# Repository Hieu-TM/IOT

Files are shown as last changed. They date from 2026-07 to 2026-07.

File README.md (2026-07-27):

# Aqua Scope — Trạm Quan Trắc & Đếm Hạt/Rác Thải Vĩ Mô Trong Dòng Chảy (1mm–5mm)

Aqua Scope là dự án chuyển đổi một cụm camera (**baseline hiện tại: ESP32-CAM AI-Thinker, OV2640**; board gốc thử nghiệm là XIAO ESP32-S3 Sense, đã thay từ 2026-07-15, nay chỉ giữ làm biến thể cơ khí tham khảo) thành một **trạm chụp ảnh và đếm hạt tự động** đặt trong một **khối trụ chắn sáng**, camera nhìn thẳng xuống một **dòng chảy nước hở** để **phát hiện, đếm và đo kích thước** các hạt nhựa/rác thải vĩ mô cỡ **1mm – 5mm**.

> **Phạm vi trung thực về vật lý:** Hệ này **đếm và đo kích thước hạt/rác trong dòng chảy** bằng ảnh bóng đổ (silhouette). Nó **không** phân biệt hóa học "hạt này là nhựa hay không phải nhựa" — việc đó cần nhuộm huỳnh quang (Nile Red) và được ghi nhận là **hướng mở rộng tương lai**, không nằm trong baseline.

---

## Chạy hệ thống (đường ngắn nhất)

Bấm đúp **`start.bat`** ở thư mục gốc. Nó tự tạo môi trường ảo, cài thư viện ở
lần đầu, khởi động backend và mở `http://localhost:8000`.

Backend chạy trong một **cửa sổ PowerShell riêng** tên **"Aqua Scope Server"**
mà `start.bat` mở ra; cửa sổ `start.bat` ban đầu tự đóng ngay sau đó — đó là
bình thường, không phải lỗi. Muốn dừng server thì bấm **Ctrl+C** hoặc đóng
cửa sổ **"Aqua Scope Server"** (không phải cửa sổ đã đóng).

> **Trước khi bấm Bắt đầu:** `ml/config.toml` mặc định `backend = "local"`,
> nhưng repo này **không** kèm sẵn `ml/models/best.pt` (weights không commit
> được) và `ml/requirements-infer.txt` cũng cố tình không cài ultralytics/
> torch — nên trên một máy mới clone, bước 4 dưới đây sẽ báo lỗi 400
> "local.weights not found". Chọn một trong hai hướng trước:
> * đổi sang `backend = "roboflow"` trong `ml/config.toml` và điền
>   `roboflow.api_key` (+ workspace/workflow_id) vào `ml/config.local.toml`
>   (file này gitignore, không commit key); hoặc
> * cài `pip install -r ml/requirements.txt` rồi tự train/đặt weights vào
>   `ml/models/best.pt` (xem `[local]` trong `ml/config.toml`).

Trên dashboard:

1. Bấm **Dò** — tìm board qua `aqua-scope.local`. Không thấy thì gõ IP tay
   (Serial Monitor 115200 in ra IP lúc board khởi động).
2. Bấm **Canh sáng buồng tối** rồi **Lưu vào flash** (chỉ cần làm một lần cho
   mỗi rig — cấu hình được nhớ qua các lần mất điện).
3. Bấm **Bơm auto BẬT**.
4. Chọn **Xem** hoặc **Đo**, rồi bấm **Bắt đầu**.

Mỗi chu kỳ bơm sinh một khung ở pha lắng (SETTLING); hệ thống chạy tới khi bấm
**Dừng** — không còn giới hạn số ảnh.

| Chế độ | Ghi vào sổ audit? | Dùng khi |
|---|---|---|
| **Xem** | Không | canh sáng, chỉnh rig, thử nghiệm |
| **Đo** | Có, mỗi chu kỳ một mẫu | đo thật, cần truy xuất nguồn gốc |

> **Cảnh báo triển khai:** backend lắng nghe trên `0.0.0.0:8000` để mở được từ
> điện thoại trong cùng LAN, và **không có xác thực**. Đây là rig demo trong
> mạng nội bộ — đừng chuyển tiếp cổng này ra Internet.
>
> Chế độ **Đo** chạy dài sẽ tích ảnh trong `web/backend/data/images/`
> (~300KB/mẫu, chu kỳ 15s ≈ 70MB/giờ). Chưa có dọn rác tự động — tự theo dõi
> dung lượng đĩa nếu chạy nhiều giờ liền.

---

## 🎯 Bối Cảnh Ứng Dụng (Use Case)

**Kiểm soát chất lượng nước đầu vào cho nhà máy chế biến thực phẩm.** Hệ được đặt ở **điểm lấy nước đầu vào**, kiểm tra nước **trước khi** đưa vào dây chuyền sản xuất, nhằm phát hiện và định lượng hạt/rác vĩ mô (1–5mm) lẫn trong nguồn nước.

Đặc điểm bối cảnh này định hình các quyết định thiết kế:

| Đặc điểm bối cảnh | Hệ quả cho thiết kế |
|---|---|
| **Mẫu ổn định** (nước máy/nguồn cấp, không phải nước thải bẩn biến động mạnh) | Nền sáng đều và ngưỡng hóa (threshold) cố định là đủ tin cậy; không cần bù trừ nền phức tạp. |
| **Lấy mẫu định kỳ** (theo lô/theo ca, không phải giám sát liên tục 24/7) | Chu trình **Stop-Flow** rất hợp: mỗi lần đo là một mẫu rời rạc, có thời gian settle; không cần throughput cao. |
| **Yêu cầu truy xuất nguồn gốc (traceability)** | **Bắt buộc**: mỗi lần đo phải gắn **mã mẫu / timestamp / số hạt / phân bố kích thước** và **lưu lại (log)** để đối chiếu về sau. Đây là yêu cầu chức năng mới, không chỉ "đếm là xong". |

> **Lưu ý phạm vi:** đây là kiểm nước đầu vào của nhà máy thực phẩm, **không phải** thiết bị đạt chuẩn an toàn thực phẩm/y tế được chứng nhận. Baseline là **rig demo/phòng lab** minh họa quy trình kiểm định, không phải thiết bị thương mại đã kiểm chuẩn.

---

## 📌 Tiêu Chí Cốt Lõi (3 KHÔNG)

1. **KHÔNG chỉnh sửa thấu kính**: Giữ nguyên lens gốc. Thực nghiệm cho thấy lens gốc OV2640 **tự lấy nét macro sắc nét ở cự ly 3–5cm** — nên chỉ cần đặt mẫu đúng khoảng cách đó, **không cần vặn hay thay lens**.
2. **KHÔNG dùng chip vi lưu kín**: Hạt 1–5mm sẽ làm tắc/rò các kênh micron của flow-cell kín (như [pone.0244103.pdf](file:///c:/University/Semester%204/IOT102/project/pone.0244103.pdf)). Thay bằng **khay dòng chảy hở (Macro-Flow Stage)** + **mực nước cố định bằng mép tràn (weir)** và (tùy chọn) một **cửa sổ kính phẳng cố định** để làm phẳng mặt nước.
3. **KHÔNG can thiệp thủ công**: Bơm, chiếu sáng, chụp ảnh, đếm và xả đều tự động. *(Ngoại lệ thực tế: cần vệ sinh định kỳ chống bám bẩn/tảo khi dùng ngoài thực địa — hệ baseline định vị ở mức demo/phòng lab.)*

---

## 🏗️ Kiến Trúc Vật Lý

Khối trụ chắn sáng **ngắn** (~4–5cm), camera úp xuống từ nắp trụ, đèn nền trắng khuếch tán chiếu ngược từ dưới đáy khay trong suốt lên.

```mermaid
graph TD
    subgraph "Khối Trụ Chụp Ảnh (Imaging Tube)"
        T3["Nắp trụ tháo được: Camera ESP32-CAM (AI-Thinker) úp thẳng xuống"]
        T2["Thân trụ chắn sáng (~4-5cm): cố định cự ly nét 3-5cm + buồng tối"]
        T1["Đáy: Khay dòng chảy hở, đáy TRONG SUỐT (đĩa acrylic tròn); mực nước giữ bằng bơm-tắt (van tự chặn)"]
        B["Hộp đèn nền (Light Box): đèn chiếu GIÁN TIẾP vào nền trắng, ánh sáng dội ngược lên"]
    end

    subgraph "Trạm Bơm (đặt tách rời)"
        P["Bơm màng RS365 12V (chủ động hút/đẩy) + lưới thô >5mm ở cổng vào"]
    end

    P -->|Hút chuỗi: nguồn→khay→bơm→thải, ống ID≥6mm| T1
    T3 -->|Nhìn vuông góc, cự ly 3-5cm| T1
    B -->|Ánh sáng xuyên đáy trong| T3
```

### Vai trò của khối trụ (xương sống của hệ, không phải cái vỏ)
1. **Thước đo (datum):** cố định **cứng** cự ly camera↔nước → giữ **mm/pixel** ổn định → đo kích thước hạt đúng.
2. **Buồng tối:** chắn ánh sáng môi trường → phơi sáng ổn định, ngưỡng hóa (threshold) đáng tin.
3. **Chân máy:** tiết diện lớn, ngắn → cứng, chống rung → ảnh nét, khung hình không lệch.
4. **Nhà đèn:** giữ đèn nền + thành trong **sơn đen nhám** để hút phản xạ lạc.

Chuỗi phụ thuộc: `chiều cao ống → cự ly camera-nước → FOV → mm/pixel → hạt nhỏ nhất thấy được`. Vì lens nét ở 3–5cm nên ống ngắn ~4–5cm; ở cự ly này khay **lấp gần đầy khung hình** và **1mm ≈ 14–35 pixel** (tùy độ phân giải ảnh), thừa để đếm.

> **🔒 Hình dạng & lắp nắp (chốt):** thân trụ là **ống trụ THẲNG**, đường kính ngoài **bằng đúng footprint của base Matchboxscope ĐÃ IN (~50×52mm)** — **KHÔNG phình rộng thành "cốc"**, và **nắp trụ chính là base đã in** (tái dùng nguyên bản, bắt vít qua lỗ sẵn), không dựng nắp mới. Thử nghiệm cho thấy ống thẳng cho ảnh **không kém** ống rộng — chất lượng silhouette do **nội thất đen nhám + phơi sáng tay** quyết định, không do bề rộng ống. Vì nắp (base) chỉ ~50mm nên khay/cửa sổ acrylic/đèn nền **co theo cho lọt lòng ống** (`tube_id`≈46mm → vùng nước ảnh hóa ~40mm, vẫn lấp gần đầy khung, 1mm ≥ ~13px ở VGA).

---

## 🔬 Chiếu Sáng: Bóng Đổ Nền Sáng (Backlit Silhouette)

Đèn LED **trắng** đặt **dưới** đáy khay trong suốt, chiếu ngược lên qua nước. Hạt hiện thành **bóng đen sắc nét trên nền sáng đều**. Đây là kỹ thuật đo hạt kinh điển (shadowgraphy).

### Hộp đèn nền (Light Box) — "LED XUÔI" + buồng trộn + màng khuếch tán xếp lớp

> **🔒 CHỐT 2026-07-07 (thay phương án "bounce/baffle" cũ):** dùng **"LED xuôi"** — module LED
> dựng đứng, **đầu LED hướng THẲNG LÊN**, phía trên có **buồng trộn ~8mm** rồi **màng khuếch tán
> xếp lớp** (giấy can/mica mờ, thêm/bớt lớp chỉnh độ tán) ngay dưới đáy khay. Lý do: test thực tế
> với khuếch tán lớp giấy cho kết quả chấp nhận được; nước cấp nhà máy sạch/ổn định nên nguồn xuôi
> là đủ, kết cấu đơn giản hơn hẳn bounce. (Chi tiết: `thiet_ke_hop_den_nen.md`.)

Kết cấu xếp lớp từ dưới lên:

```
        [ Đáy khay: ĐĨA ACRYLIC trong suốt ]   ← hạt nằm trên đây
   ┌────────────────────────────────────┐
   │  MÀNG KHUẾCH TÁN xếp lớp 0–4mm      │  ← giấy can / mica mờ (chỉnh được)
   ├────────────────────────────────────┤
   │  BUỒNG TRỘN ~8mm (khử hotspot)      │
   │            ▲ LED                    │  ← module LED móc khoá 37.5×10×16
   │       [vách đỡ RỜI, 2 ốc M3 ngang]  │     dựng đứng, đầu LED hướng LÊN,
   │        nửa pin dưới vách            │     cắm-tháo ma sát qua lỗ vách
   └────────────────────────────────────┘
        vành đáy ống = chân đế (hở giữa để thay pin/thao tác)
```

- **Cả module móc khoá = "1 bóng"**: xỏ qua lỗ giữa vách đỡ (khe +0.4mm, giữ ma sát, không keo).
- **Vách đỡ là MIẾNG RỜI** nằm giữa lòng ống, bắt **2 ốc M3 xuyên ngang thành ống** — tháo 2 ốc
  là gỡ cả vách + module.
- **Mặt trong khoang đèn TRẮNG mờ** (khác thân trụ quang học đen nhám) để sáng đều thêm.
- **Màng khuếch tán là lớp bắt buộc**: nguồn điểm → nền xám đều; camera không bao giờ thấy LED trần.

### Bắt buộc để không bị cháy sáng (đúc kết từ thực nghiệm)
- **Khuếch tán** ánh sáng qua tấm mờ (acrylic mờ / giấy can) → nền **xám đều**, không có đốm chói.
- **Phơi sáng thủ công** trên firmware: **tắt AEC (auto exposure), tắt AEC DSP, tắt AGC (auto gain)**, đặt **Gain = 0** và **Exposure thấp**. *(Nếu chỉ kéo thanh Exposure mà chưa tắt AEC/AGC thì cảm biến ghi đè → luôn cháy trắng.)*
- **Vùng sáng lấp đầy khung hình**, tránh viền đen lớn (viền đen vừa phí pixel vừa đánh lừa auto-exposure).
- **Nếu dùng đèn pin mini (kiểu lồng đèn):** độ sáng yếu dần khi pin cạn → khóa phơi sáng tay rồi chỉnh Exposure khớp độ sáng thực; nếu đèn RGB/nhấp nháy thì **phải đặt về trắng tĩnh (static white)**, màu đổi sẽ làm nền chập chờn hỏng ảnh.

### Giảm cường độ khi sáng quá mạnh
- **Khuếch tán/làm đều:** 1–2 lớp **giấy can** hoặc **mica mờ** (mica bền hơn giấy khi gần nước; giấy dễ ẩm, cong).
- **Giảm độ sáng:** chồng thêm **giấy trắng thường** hoặc **phim ND (Neutral Density)** (ND giảm sáng không đổi màu).
- **Cách "sạch" nhất — hạ dòng đèn:** dùng **PWM/chiết áp/điện trở lớn hơn** để chỉnh vô cấp, ưu tiên cách này để tinh chỉnh cuối. *(Làm trước hết vẫn là khóa phơi sáng tay — nhiều ca "cháy sáng" là do AEC/AGC chứ không phải đèn quá mạnh.)*

---

## 🌊 Hệ Dòng Chảy (đơn giản, không kẹt)

- **Dòng chảy do BƠM CHỦ ĐỘNG** (không dựa trọng lực): một **bơm màng RS365 12V** (tự mồi) đặt ở **đầu ra**, hút cả chuỗi **nguồn → khay → bơm → thải**. Bật bơm thì nước (và hạt) bị kéo qua; **tắt bơm** thì **van 1 chiều trong bơm tự bịt, GIỮ NGUYÊN mực nước** để settle — **không cần mép tràn/standpipe để giữ mực** (xem ghi chú "Giữ mực & chống đọng").
- Nước mẫu + hạt vào khay qua **ống rộng** + **lưới thô khe >5mm** ở cổng vào (chỉ **chặn rác to** như lá/cành, **không lọc mất hạt cần đo**).
- **Nước luôn vào–ra qua cổng ở THÀNH BÊN** (theo phương ngang), **không đổ từ trên xuống băng qua cửa sổ** — tránh che tầm nhìn camera và tránh khuấy động mặt nước. Đĩa acrylic ở đáy chỉ có **nước đứng yên bên trên và ánh sáng bên dưới**.
- **2 cổng thành bên, ĐỐI TÂM 180°** để dòng quét ngang TOÀN sàn: (1) **VÀO** — biến tia thành **màng rộng sát đáy** bằng **khe khuếch tán (~18–22mm × ~3mm)** để xóa 2 thùy tĩnh hai bên và quét mặt đáy; qua lưới >5mm nối **nguồn mẫu**. (2) **RA — cổng rút SÁT ĐÁY** (KHÔNG phải ở đỉnh 6mm) nối **ống hút bơm RS365 → thải**, để lúc flush hút được cả **hạt CHÌM (PET/PS) nằm ở đáy**.
- **Mực nước 6mm** do **thời lượng bơm + van bơm tự chặn** ấn định. **Mép tràn (weir) hạ xuống vai trò TÙY CHỌN** (chặn-tràn an toàn khi fill + mực lặp lại), không còn là cơ cấu bắt buộc. **Van xả đáy** cũng tùy chọn (xả cạn/vệ sinh).
- **Chống đọng — yêu cầu duy nhất của khay là "mọi hạt phải RA HẾT, không sót":** **bo fillet R≥2.5mm** góc đáy–thành; **mặt đĩa acrylic phẳng bằng sàn + silicon vê tròn** mối nối để xóa rãnh bẫy hạt; **TUYỆT ĐỐI không lưới/gờ giữ hạt** (việc "giữ hạt lúc chụp" là do **bơm TẮT**, không do cơ học). Flush = **bơm chạy mạnh** (vận tốc khay ~10 cm/s ≈ Q ~1.4 L/min) đủ nhấc cả hạt nổi lẫn chìm ra cổng RA. **Kiểm bằng thả ~20 hạt rồi đếm hạt sót.**
- Ống **ID ≥ 6mm (≥3× hạt 2mm)** để không kẹt; nút hẹp thật sự là **van 1 chiều trong bơm** (bệ ~2–4mm). **Bơm tách rời khối quang** để cách ly rung chấn; nối khay bằng **ống của bơm RS365 đường kính 8mm** *(mặc định hiểu là ID danh nghĩa ~8mm → cổng/ngạnh khớp 8mm; nếu 8mm là OD thì ID~6, cần xác nhận)*. Điện: RS365 12V qua **MOSFET IRLZ44N + diode flyback 1N4007 + tụ 470–1000µF**, nguồn **adapter 12V/2A**, ESP32 nuôi riêng (USB 5V hoặc buck 12V→5V), **chung GND**.

### Độ dày lớp nước (~6mm) — vì sao phải MỎNG
Hạt nhựa **nổi HOẶC chìm** (PE/PP nổi ở mặt nước; PET/PS chìm ở đáy acrylic) → hạt nằm ở **2 mặt phẳng** cách nhau đúng bằng độ dày nước. Giữ nước **mỏng** để:
- **Cả hạt nổi lẫn hạt chìm cùng nằm trong vùng nét (DOF)** — nước sâu thì một trong hai lớp bị nhòe → đo sai kích thước.
- **Chống hạt xếp chồng theo phương đứng** (2 bóng đè nhau → đếm sai); nước mỏng ép hạt thành gần-một-lớp.

Sàn dưới = **hạt lớn nhất 5mm + ~1mm dư ⇒ chọn ~6mm**. Kèm theo: **lấy nét ở GIỮA lớp nước (~3mm)** để hạt nổi/chìm cách mặt nét đều nhau; và **phải kiểm DOF trên phần cứng thật** — nếu DOF của lens gốc ở 40mm < 6mm thì hạt nổi sẽ nhòe → hạ xuống 5mm (tham số hóa).

### Vì sao chuyển sang bơm màng chủ động (bỏ nhu động 28BYJ-48 + bỏ trọng lực)
Bơm nhu động 28BYJ-48 (tham khảo Planktoscope Mini) **bị loại vì quá chậm**: hộp số 1/64 → trục ra ~10–15 RPM, kịch trần ~40 RPM (mô-men sụt theo bậc), lưu lượng thực chỉ **vài mL/phút** → đổ đầy khay 7–10 mL mất **hàng phút**, trong khi ESP32-S3 xử lý xong tức thì. Bơm là **nút cổ chai duy nhất**. Ép nó nhanh (full-step, quá áp, bỏ hộp số) đều đi ngược bản chất "định lượng lưu lượng thấp".

Baseline dùng **bơm màng RS365 12V chủ động** cho toàn bộ fill/flow/flush:

| Việc | Ai làm |
|---|---|
| Cấp mẫu **VÀO** + tạo dòng | **Bơm RS365** hút chuỗi nguồn→khay→bơm→thải |
| **Giữ mực nước** khi chụp | **Van màng bơm tự chặn khi TẮT** (mép tràn = tùy chọn chặn-tràn, không bắt buộc) |
| **Xả/flush hạt** ra ngoài | **Bơm RS365** chạy mạnh/lâu hơn, cuốn hạt (nổi + chìm) ra **cổng ra sát đáy** → thải |

> **Đánh đổi (ghi trung thực):** dòng chủ động khiến **hạt đi qua bơm** ở phía cổng ra — khác thiết kế gốc *"hạt không bao giờ qua bơm"*. Chấp nhận được vì **phạm vi test là hạt < 2mm**, nhỏ hơn nhiều bệ van màng (~2–4mm). Nếu sau này quay lại dải 5mm thì **phải xét lại** (5mm cứng sẽ kẹt van). Bơm chìm 5V bị loại vì phải ngâm nước (khuấy mặt nước + phơi nhiễm hạt) và **cháy khi chạy khô**.

### Cấu tạo đáy khay: đĩa acrylic tròn + chống rò
Đáy trong suốt dùng **đĩa acrylic (mica) TRONG** cắt tròn làm "cửa sổ". Nhựa in 3D **không cho sáng xuyên đều** (các lớp in tán xạ), nên chỉ dùng in 3D làm **khung đen chắn sáng**, còn cửa sổ sáng là **tấm trong rời lắp vào**. **Chọn acrylic thay lam kính** vì lam kính cố định kích thước (rộng chỉ 26mm) không phủ được khay tròn Ø40 → phải bóp vùng ảnh nhỏ; **acrylic cắt được đĩa tròn Ø bất kỳ** nên **giữ nguyên khay tròn, vùng ảnh lấp đầy khung**. Chụp silhouette không cần độ trong quang học cao (hạt nằm ngay trên tấm, đèn đã khuếch tán) nên acrylic thừa trong.

> **Tách 2 lớp — đừng gộp:** cửa sổ đáy = **acrylic TRONG** (để bóng hạt nét); tấm khuếch tán = **mica MỜ/giấy can RIÊNG** đặt bên dưới (để đều sáng). Hai chức năng, hai tấm.

Kiểu lắp **gờ đỡ + vòng ép + silicon**:

```
   mặt cắt cạnh khay:
   ┌── vòng ÉP (retainer, vặn vít/ngàm cài) ──┐
   ═════════ ĐĨA ACRYLIC TRONG ═════════       ← ép giữa 2 lớp
   ░silicon░                        ░silicon░   ← keo silicon hồ cá
   └─ gờ KÊ (ledge) ─┐        ┌─ gờ KÊ ─┘
        thành nhựa in 3D (đen mờ)
```

- **Kích thước đĩa:** cắt **Ø hơi lớn hơn miệng khay** (VD Ø42 cho khay trong Ø40, lọt bore ID46) để có mép chồng lên gờ; **dày 2–3mm** (đĩa Ø~42 không võng), ưu tiên **acrylic đúc (cast)**.
- **Gờ kê (ledge):** hốc lõm quanh miệng khay, ăn vào trong ~2.5mm, sâu ≈ (độ dày đĩa + ~0.3mm cho silicon).
- **Chống rò:** bơm viền mỏng **silicon trung tính (keo hồ cá)** lên gờ **trước khi** đặt đĩa, ấn nhẹ cho dàn đều. **KHÔNG dùng keo 502/cyanoacrylate** — hơi keo làm **acrylic mờ trắng (fogging)**. Không lau bằng dung dịch gốc amoniac (gây rạn).
- **Giữ cố định:** một **vòng ép in 3D thứ hai** đè lên viền đĩa, bắt **3–4 vít M2.5** hoặc ngàm snap-fit → vừa kín, vừa không cho đĩa trôi/nổi.
- **Dung sai in:** chừa khe **+0.3–0.4mm** quanh đĩa; in khung **đen mờ, mặt trong tối** để chắn sáng lạc.
- **Acrylic dễ xước** → vết xước có thể đọc thành "hạt ảo"; thiết kế cửa sổ là **chi tiết thả-vào thay được**, lau nhẹ bằng khăn mềm.
- Tùy chọn (đúng "3 KHÔNG" #2): thêm **1 tấm phẳng gác trên gờ phía trên** (acrylic hoặc lam kính) làm **cửa sổ ép phẳng mặt nước** — **gác gờ, không thả nổi** (kính/acrylic nặng hơn nước sẽ chìm). Lam kính đang có tận dụng ở đây hoặc để hiệu chuẩn.

---

## ⚙️ Chu Trình Vận Hành (Stop-Flow)

```mermaid
sequenceDiagram
    autonumber
    participant Bom as Trạm Bơm
    participant Den as Đèn Nền Trắng
    participant Cam as Camera (ESP32-CAM)
    participant CV as Xử lý ảnh (PC/laptop qua ml/)

    Note over Bom, CV: B1: Cấp mẫu
    Bom->>Bom: Bơm RS365 hút chuỗi nguồn→khay→thải, khay đầy tới mép tràn

    Note over Bom, CV: B2: Đóng băng (Settle)
    Bom->>Bom: TẮT bơm 1-2s; van màng bơm tự chặn giữ mực nước, mặt nước phẳng lại

    Note over Bom, CV: B3: Chụp ảnh
    Den->>Den: Bật đèn nền trắng (ổn định)
    Cam->>Cam: Chụp ảnh độ phân giải CAO (SXGA/UXGA)

    Note over Bom, CV: B4: Đếm & Đo + Phân loại
    CV->>CV: PC/laptop kéo ảnh, chạy YOLO (local hoặc Roboflow) → bbox + class + confidence; size_mm = max(w,h) / px_per_mm

    Note over Bom, CV: B5: Xả mẫu
    Den->>Den: Tắt đèn
    Bom->>Bom: Bơm RS365 chạy mạnh cuốn hạt ra cổng ra → thải, nạp mẫu mới → lặp
```

> **Vì sao PHẢI dừng dòng khi chụp (Stop-Flow là bắt buộc, KHÔNG phải di sản bơm nhu động):** dừng dòng cần cho **quang học + thuật toán**, độc lập với loại bơm:
> 1. **Rolling shutter** của OV2640 (mỗi hàng pixel phơi sáng lệch giờ) làm hạt đang trôi **méo hình (skew) + nhòe** → sai phép **ĐO KÍCH THƯỚC**. (Chụp lúc chảy cần global shutter hoặc đèn strobe freeze — hệ này không có.)
> 2. Mặt nước chảy **gợn sóng** → khúc xạ bóng hạt, lệch vị trí/kích thước biểu kiến. Settle 1–2s làm mặt phẳng lại.
> 3. Đếm cần **mẫu RỜI RẠC, thể tích cố định** (1 ảnh = N hạt trong diện tích khay × 6mm) → quy ra nồng độ + truy xuất nguồn gốc.
> 4. Pipeline `threshold → connected components → count` là thuật toán **MỘT KHUNG** → chạy trên dòng đang chảy sẽ **đếm đôi** cùng một hạt.
>
> ⇒ Bơm màng RS365 nhanh **làm Stop-Flow TỐT HƠN** (Fill/Flush chớp nhoáng → chu kỳ ngắn, nhiều mẫu/phút), **không hề làm nó thừa**. Thứ *thực sự* đã lỗi thời (thời nhu động) là logic "trọng lực đổ đầy / bơm chỉ chuyển nước sạch / xả van đáy" — xem `info.txt §5–6`.

---

## 🧠 Xử Lý Ảnh

**Hiện trạng đang chạy:** ESP32-CAM chỉ chụp/phục vụ ảnh (`/capture`, `/stream`); một PC/laptop kéo ảnh về và chạy **YOLO** (local `ultralytics` hoặc Roboflow Workflow API — xem `ml/deploy_options.md`) để lấy bbox + class + confidence, suy ra `size_mm = max(w,h) / px_per_mm`, rồi gửi kết quả lên backend. Lý do offload: board ESP32-CAM hiện dùng (ESP32 thường) không có lệnh vector AI như dòng S3 mà thiết kế gốc bên dưới giả định.

**Thiết kế gốc (viết cho phần cứng XIAO ESP32-S3, chưa áp dụng lại được trên ESP32-CAM hiện tại):** pipeline lai — **classical CV** lo **đếm + đo kích thước** (chính xác, rẻ, không cần train), rồi **classifier nhỏ on-device** lo **phân loại từng hạt là GÌ**.

**Vì sao KHÔNG để object detection làm hết (lý do gốc, khi còn nhắm tới on-device S3):** FOMO trên XIAO S3 chạy input ~96×96, ~143ms/~7fps nhưng **chỉ trả centroid, KHÔNG trả kích thước**; ở FOV ~40mm thì 96×96 ≈ 0.42mm/px → hạt <2mm chỉ ~5px, dễ mất hoặc dính chùm sau downsample. Lập luận này áp dụng cho FOMO/end-to-end detection *chạy trên chip*; pipeline YOLO hiện tại chạy trên PC nên không bị giới hạn 96×96 đó, nhưng đổi cách tính size từ "connected components" sang "bbox / px_per_mm" — hai cách này CHƯA được đối chiếu độ chính xác với nhau.

**Pipeline gốc (dự kiến, chưa chạy trên phần cứng hiện tại):**
1. **Chụp phân giải cao** (SXGA/UXGA) → ảnh xám → **ngưỡng hóa** (vùng tối trên nền sáng) → **connected components** → mỗi blob cho **tâm + diện tích → đếm & phân bố kích thước**.
2. **Crop từng blob** → đưa vào **classifier nhỏ** (TinyML, tận dụng lệnh vector AI của S3) → **gán loại hạt**. *(Danh sách lớp cụ thể — ví dụ nhựa / bọt khí / rác hữu cơ / sợi — sẽ chốt sau khi có dữ liệu mẫu thật.)*

**Phần cứng dự kiến cho pipeline gốc:** chạy **on-device** trên XIAO ESP32-S3 (PSRAM 8MB, 240MHz, có lệnh vector AI) — không phải phần cứng ESP32-CAM đang dùng hiện tại.

*(Phân biệt nhựa/không-nhựa bằng hóa học vẫn là hướng mở rộng: nhuộm Nile Red + LED 365nm + kính lọc vàng → cấp thêm đặc trưng màu cho nhánh classifier, không thuộc baseline.)*

---

## 🗒️ Lịch Sử Thiết Kế (vì sao baseline hiện tại khác bản đầu)

Bản ý tưởng đầu (huỳnh quang UV + FOMO + kính nổi + cự ly 10–15cm + cột Z-Axis) đã được **sửa lại sau khi kiểm tra vật lý và thực nghiệm**:

| Vấn đề bản cũ | Sửa trong baseline |
|---|---|
| UV không làm đa số nhựa (PE/PP/PET/PS) phát quang; rác hữu cơ lại phát quang | Đổi sang **backlit silhouette** ánh sáng trắng, phát biểu mục tiêu trung thực (đếm hạt, không nhận dạng hóa học) |
| FOMO 96×96 không thấy hạt <2mm, không trả kích thước | **Hybrid**: classical CV đếm+đo (size chính xác) + **classifier** phân loại từng hạt (dùng thế mạnh AI của S3) |
| Kính thủy tinh "thả nổi" sẽ chìm | **Cửa sổ kính cố định + mép tràn** giữ mực nước phẳng |
| Bơm nhu động 28BYJ-48 quá chậm (~vài mL/phút) | **Bơm màng RS365 12V chủ động** lo fill/flow/flush; chấp nhận hạt <2mm qua bơm (đánh đổi có chủ đích) |
| Cự ly 10–15cm + lens gốc → hạt bé, phí pixel, cột conson rung | Thực nghiệm: lens gốc **nét ở 3–5cm** → ống **ngắn, cứng**, khay lấp đầy khung |

---

## 📁 Cấu Trúc Thư Mục

* [info.txt](file:///c:/University/Semester%204/IOT102/project/info.txt): Báo cáo kỹ thuật chi tiết (Tiếng Việt).
* [implementation_plan.md](file:///c:/University/Semester%204/IOT102/project/implementation_plan.md): Kế hoạch dựng mô hình 3D OpenSCAD + bảng hằng số baseline.
* [technical_specs.md](file:///c:/University/Semester%204/IOT102/project/technical_specs.md): Thông số cơ khí trích xuất từ các tệp STL tham khảo.
* `plan.md`: Kế hoạch build mô hình 3D (quyết định chốt G1–G5 + thứ tự + kiểm chứng).
* [`thiet_ke_hop_den_nen.md`](file:///c:/University/Semester%204/IOT102/project/thiet_ke_hop_den_nen.md): Chi tiết thiết kế hộp đèn nền "LED xuôi" (chốt 2026-07-07).
* `HUONG_DAN_LAP_RAP.md`: Tutorial thực thi — từ chi tiết đã in/đã mua → lắp trạm hoàn chỉnh → nạp firmware.
* `ai_model_plan.md`: Kế hoạch tạo & train model AI (classifier phân loại hạt) trong pipeline hybrid.
* `web_plan.md`: Spec+plan gộp bản đầu của web/backend — **đã superseded 2026-07-14**, giữ để tra cứu bối cảnh; nguồn sự thật hiện tại là cặp spec/plan trong `docs/superpowers/` (xem bên dưới).
* `openscad/` **(ĐÃ DỰNG 2026-07-07, tiếp tục sửa)**: mô hình OpenSCAD hoàn chỉnh — `constants.scad` (hằng số + assert),
  `components/*.scad` (bản mới nhất của mỗi chi tiết thắng — vd. `top_cap_004` thay `_001`–`_003`),
  `aqua_scope_assembly_001.scad` (lắp ghép tổng, cờ `explode`/`show_*`/`cam_variant`),
  `print/*.scad → *.stl` (9 chi tiết in, đã kiểm manifold). Kiến trúc **lắp từ đáy**: vỏ 1 ống liền
  (đen trên/trắng dưới), khay + đĩa acrylic + vòng ép snap-fit + màng + vách LED đều luồn/tháo từ dưới;
  2 khe dọc ±X cho ngạnh ống nước (có nút bịt chống lọt sáng). Biến thể **ESP32-CAM** (`cam_variant=1`)
  là baseline hiện tại; bản gốc XIAO chỉ còn giữ làm biến thể tham khảo.
* [base/](file:///c:/University/Semester%204/IOT102/project/base): STL bệ gốc Matchboxscope — **chính là nắp trụ** (in sẵn, tái dùng nguyên bản, không dựng nắp mới). **Đường kính thân trụ lấy đúng footprint của base (~50×52mm)**, ống THẲNG không phình rộng.
* [perestaltic pump/](file:///c:/University/Semester%204/IOT102/project/perestaltic%20pump): STL bơm nhu động Planktoscope Mini — **chỉ tham khảo, ĐÃ LOẠI** (quá chậm). Baseline dùng **bơm màng RS365 12V** chủ động.
* [`so_do/`](file:///c:/University/Semester%204/IOT102/project/so_do): Sơ đồ tổng quan hệ thống + chi tiết hộp đèn nền (SVG).
* [`firmware/`](file:///c:/University/Semester%204/IOT102/project/firmware): Firmware ESP32. Bản **chính thức**: [`aqua_scope_station/`](file:///c:/University/Semester%204/IOT102/project/firmware/aqua_scope_station) (ESP32-CAM AI-Thinker, port từ `esp32-cam-webserver` easytarget + `/device` audit + lưu cấu hình flash). Các thư mục khác (`aqua_scope_cam/`, `Esp32 cam/`, `esp32-cam-webserver/` repo lồng, `pump_stopflow_test/`) là tiền đề/tham khảo/công cụ test độc lập — xem bảng phân loại trong README của `aqua_scope_station/`.
* [`dataset_collector/`](file:///c:/University/Semester%204/IOT102/project/dataset_collector): Firmware (bản sao của `esp32-cam-webserver`, thêm nút thu dataset vào web UI) + `collect_dataset.py` + `diagnose.py` — công cụ thu ảnh dataset huấn luyện, tách riêng khỏi firmware của trạm.
* [`ml/`](file:///c:/University/Semester%204/IOT102/project/ml): Pipeline detection (Roboflow `microplastics-m7mf5`) — train/export/suy luận (2 nhánh backend Roboflow hoặc local `ultralytics`), `--from-board` chụp thẳng từ board ghi sổ audit. Xem `ml/deploy_options.md` cho 2 hướng deploy (offload PC vs on-device).
* [`web/`](file:///c:/University/Semester%204/IOT102/project/web): Backend FastAPI + dashboard truy xuất nguồn gốc (traceability) — nhận kết quả từ `ml`, phục vụ lịch sử/audit theo mã mẫu. Spec/plan hiện hành ở `docs/superpowers/specs|plans/2026-07-14-web-*`.
* [`Aqua Scope dashboard/`](file:///c:/University/Semester%204/IOT102/project/Aqua%20Scope%20dashboard): Design handoff (HTML/JSX tham chiếu, không phải code sản phẩm) cho dashboard QC ở `web/` — đã hiện thực hoá với vài lệch có chủ đích (SVG server-render thay Chart.js, bỏ Google Fonts/state-simulator).
* [`variants/`](file:///c:/University/Semester%204/IOT102/project/variants): Hướng nghiên cứu thay thế — cảm biến quang tán xạ 1D (photodiode + NeuralCasting), bỏ camera/holography và bỏ Stop-Flow. Không phải baseline, xem `variants/README.md`.
* [`docs/superpowers/`](file:///c:/University/Semester%204/IOT102/project/docs/superpowers): Spec/plan hiện hành theo chuẩn superpowers (`specs/`, `plans/`, `prompts/`) — nguồn sự thật mới nhất cho web, ml, firmware station/dataset-collector, thay cho các file `*_plan.md` rời ở gốc repo khi đã được đánh dấu superseded.

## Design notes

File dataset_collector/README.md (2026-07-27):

# Aqua Scope — Bộ thu thập dataset (ESP32-CAM)

Firmware + script để **chụp ảnh trên ESP32-CAM và kéo về laptop** làm dataset huấn luyện.

Tách riêng khỏi `firmware/` (nơi chứa 3 bản web-cam thông thường) vì đây là một
công cụ hoàn chỉnh gồm cả hai nửa: phần chạy trên board và phần chạy trên máy.

```
dataset_collector/
├── firmware/            ← nạp vào ESP32-CAM AI-Thinker
│   ├── firmware.ino         bản esp32-cam-webserver, đã cắt OTA/mDNS/NTP/portal
│   ├── app_httpd.cpp        web server — GIỮ NGUYÊN, không sửa dòng nào
│   ├── index_ov2640.h       web UI + khối "thu dataset" thêm vào
│   ├── index_ov3660.h       bản UI cho sensor OV3660 (giữ đồng bộ với trên)
│   ├── storage.{h,cpp}      lưu cấu hình camera vào SPIFFS
│   └── myconfig.h  camera_pins.h  css.h  index_other.h  src/
├── collect_dataset.py   ← chạy trên laptop: nhận ảnh (--serve) hoặc kéo ảnh
└── tests/               ← 38 test
```

## Phân chia trách nhiệm

| | Firmware | Trình duyệt | `collect_dataset.py` |
|---|---|---|---|
| Làm gì | phục vụ ảnh qua HTTP | cầu nối: lấy `/capture` rồi đẩy sang PC | ghi file vào dataset |
| Không làm gì | không biết dataset, không biết địa chỉ PC | không lưu gì | không chỉnh camera |

Firmware không mang HTTP client và không cần biết địa chỉ laptop — **toàn bộ việc
nối hai đầu nằm trong đoạn JS của trang web**. Nhờ vậy đổi cách thu dataset không
phải nạp lại firmware.

---

## Bước 1 — Nạp firmware

`dataset_collector/firmware/` là **bản sao của `firmware/esp32-cam-webserver/`**
(bản port easytarget đã sửa cho core 3.x + nút Dark), đã cắt bớt và thêm phần thu
dataset. Chọn bản này vì nó chạy **XCLK 8MHz** thay vì 20MHz — đó là nguyên nhân
của ảnh sọc/ám xanh trên các bản dựng từ ví dụ stock của Espressif.

Arduino IDE, gói board **esp32 by Espressif ≥ 3.0**:

| Mục | Chọn |
|---|---|
| Board | **AI Thinker ESP32-CAM** |
| Partition Scheme | **Huge APP (3MB No OTA/1MB SPIFFS)** |

WiFi sửa trong `myconfig.h`. Nạp: nối **IO0 → GND**, cấp nguồn, Upload, rút IO0, reset.

## Bước 2 — Canh sáng (một lần)

Mở `http://<IP>/` → bấm **Dark** (áp preset silhouette backlit) → chỉnh slider tới
khi **nền xám đều, hạt = bóng đen rõ**, không có đốm chói.

Vẫn còn sọc/ám màu? Hạ **xclk** trong Settings (8 → 6 → 4 MHz). Ảnh chậm hơn chút
nhưng sạch hơn — với Stop-Flow thì không ảnh hưởng gì.

Chỉnh xong bấm **Save** để ghi vào SPIFFS, lần sau cắm điện là đúng luôn.

## Bước 3 — Thu dataset

**Cách 1 — bấm nút ngay trên web (tiện nhất khi ngồi cạnh máy):**

```bash
python collect_dataset.py --serve          # để cửa sổ này chạy
```
Script in ra địa chỉ dạng `192.168.1.20:8765`. Điền vào ô **Dataset PC** trong
Settings của web UI (trình duyệt nhớ giúp, chỉ nhập 1 lần), đặt **Burst** = số ảnh
mỗi lần bấm, rồi bấm nút **💾 Dataset**. Trạng thái hiện ngay cạnh nút.

**Cách 2 — laptop kéo hàng loạt (khi cần số lượng lớn, không cần ngồi canh):**

```bash
python collect_dataset.py --host 192.168.1.50 --count 200 --interval 1.5
```

Ảnh lưu vào **`web/backend/data/dataset/`**, tên `YYYYmmdd-HHMMSS-mmm.jpg`.

| Tham số | Mặc định | |
|---|---|---|
| `--host` | *bắt buộc* | IP lấy từ Serial Monitor |
| `--count` | 1 | số ảnh |
| `--interval` | 1.5 | giây nghỉ giữa 2 ảnh |
| `--out` | `web/backend/data/dataset` | thư mục lưu |
| `--timeout` | 15 | timeout mỗi request |
| `--retries` | 3 | số lần thử lại mỗi ảnh |

Ctrl+C dừng giữa chừng — ảnh đã lưu vẫn còn nguyên.

---

## Vì sao lưu ở `data/dataset/` chứ không phải `data/images/`

`web/backend/data/images/` là kho ảnh **của các Sample trong DB**: mỗi file khớp
đúng một dòng, tên cứng `{sample_code}.jpg`
([ingest.py](../web/backend/app/routers/ingest.py)). Đổ ảnh thô vào đó sẽ tạo
file mồ côi — web không hiển thị được, lại lẫn với ảnh `MOCK-*` của
`mock_sender.py`. `data/dataset/` nằm cùng khu `data` nhưng không đụng vào mô
hình dữ liệu của web.

> **Lưu ý:** toàn bộ `web/backend/data/` bị **git-ignore**. Với dataset thì hợp lý
> (không nên commit hàng trăm JPEG), nhưng nghĩa là **xóa thư mục là mất trắng** —
> git không cứu được. Tự backup nếu dataset đã tốn công thu.

## Khác gì `firmware/esp32-cam-webserver/`

Toàn bộ đường camera (`StartCamera()`, `app_httpd.cpp`, prefs SPIFFS, cả 3 file
giao diện) **giữ nguyên không sửa** — đó là lý do chọn bản này. Chỉ có 2 thay đổi:

**1. Cắt 4 thư viện mạng:** OTA, mDNS, NTP, captive portal + DNSServer. Không cái
nào đụng vào camera, nhưng mỗi cái chạy task nền ăn heap — thứ ESP32-CAM vốn đã
thiếu khi chụp UXGA. Đo được: **41% → 39% flash, 75.9KB → 69.7KB RAM tĩnh.**

Các biến cờ (`otaEnabled`, `haveTime`, `captivePortal`) được giữ lại và đặt cứng
`false` vì `app_httpd.cpp` tham chiếu tới chúng — nhờ vậy file đó không phải sửa
một dòng nào.

**2. Thêm khối thu dataset vào web UI:** nút **💾 Dataset**, ô **Dataset PC**, ô
**Burst**, và dòng trạng thái. Thêm vào **cả** `index_ov2640.h` lẫn
`index_ov3660.h` — giao diện được chọn theo sensor lúc chạy, chỉ thêm một file thì
gặp board sensor khác là mất nút mà compile vẫn sạch.

## Ảnh trắng xóa / hỏng → chạy `diagnose.py` trước

```bash
python diagnose.py --host 192.168.1.50
```

Nó tắt đèn GPIO4 + mọi chế độ tự động, rồi **quét exposure từ 0 đến 1200** và đo
độ sáng từng ảnh. Kết quả trả lời dứt điểm một câu hỏi:

| Kết quả | Nghĩa là |
|---|---|
| Ảnh tối dần khi giảm exposure | Phần cứng bình thường, chỉ là canh sáng. Công cụ in luôn mức exposure nên dùng. |
| **Trắng ở mọi mức exposure** | Cảm biến không phản ứng. Chỉnh thông số vô ích → soi ánh sáng lọt vào, cáp ribbon, module. |

Đừng đoán mò khi ảnh trắng — hai trường hợp trên nhìn giống hệt nhau nhưng cách
sửa ngược nhau hoàn toàn.

**Nghi phạm số 1 khi trắng ở cả stream lẫn capture:** đèn flood **GPIO4** ngay
cạnh ống kính. `app_httpd.cpp` bật nó cho cả hai đường khi `lamp` ≠ 0 hoặc
`autolamp` bật. Trong ống chụp kín, nó bật là trắng xóa. Giữ **Light = 0**.

## Trục trặc khác

| Hiện tượng | Nguyên nhân thường gặp |
|---|---|
| **Ảnh sọc ngang / ám xanh lục** | XCLK quá cao. Hạ `xclk` trong Settings: 8 → 6 → 4 MHz. |
| Ảnh lỗi liên tục, board reset | **Brownout**: WiFi TX + chụp UXGA cùng lúc. Giảm Burst, tăng `--interval`, dùng nguồn 5V ≥ 2A. |
| Nền trắng xóa, không thấy hạt | Chưa bấm **Dark**, hoặc chỉnh xong quên bấm **Save**. |
| Bấm Dataset → `khong ket noi duoc ...` | Chưa chạy `collect_dataset.py --serve`, hoặc nhập sai IP/cổng, hoặc Windows Firewall chặn cổng 8765. |
| Bấm Dataset → `PC tu choi (HTTP 400)` | Ảnh tới nơi bị hỏng (thường do brownout giữa lúc truyền). Ảnh hỏng **không** được ghi vào dataset. |

## Chạy test

```bash
cd dataset_collector
python -m pytest tests/ -q      # 38 test
```

- **Chiều kéo + chiều nhận** đều test bằng **HTTP server thật** trên localhost,
  không mock `requests` — các kiểu hỏng cần bắt đều nằm ở tầng giao thức (body
  cụt, trả HTML kèm HTTP 200, preflight CORS, Content-Length nói dối), mock sẽ bỏ lọt.
- **Giao diện web** được kiểm bằng cách đối chiếu ID: mọi `getElementById` phải có
  phần tử tương ứng trong HTML, và khối JS ở 2 file index phải giống hệt nhau. Gõ
  sai một ID thì firmware vẫn compile sạch, vẫn nạp được, chỉ tới lúc bấm nút mới
  phát hiện im ru — đây là loại lỗi trình biên dịch không bao giờ thấy.

## Khác gì `ml.infer --from-board`

Hai công cụ, hai mục đích, cố ý không gộp:

| | `collect_dataset.py` | `ml.infer --from-board` |
|---|---|---|
| Mục đích | thu ảnh thô để **train** | đo mẫu thật để **ghi sổ audit** |
| Đầu ra | file JPEG trong `data/dataset/` | dòng Sample + Particle trong DB |
| Chạy suy luận | không | có |

Gộp lại sẽ buộc công cụ thu dataset phải mang theo cả detector lẫn kết nối DB
— hai thứ nó không cần.

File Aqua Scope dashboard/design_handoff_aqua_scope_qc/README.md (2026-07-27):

# Handoff: Aqua Scope — QC Dashboard

## Overview
Aqua Scope is a read-only QC dashboard for a water-quality monitoring station in a food-processing plant. It traces particle samples captured by a backlit imaging device (`aquascope-01`): dashboard overview, a filterable history/audit table, a per-sample detail view (image + bbox overlay + particle table + histogram + raw JSON), and a live "stream demo" canvas simulation. UI copy is Vietnamese throughout. Data model is append-only — there are no edit/delete affordances anywhere by design.

## About the Design Files
The files in this bundle (`Aqua Scope QC.dc.html`, `support.js`) are **design references built in HTML/React-like JSX**, not production code to copy directly. They render as a single-page app with client-side view switching (no router, no backend — all data is a hardcoded mock array and synthetic image generation). Your task is to **recreate this design in the target codebase's actual stack** (its component library, routing, state management, real API calls) — reproducing the exact layout, spacing, color, typography, and interaction behavior described below, not the literal markup.

## Fidelity
**High-fidelity.** Colors, spacing, type sizes, and component states are final. Treat hex/px values below as exact. The particle bbox synthesis and canvas stream simulation are demo-only stand-ins for a real detection feed/image — implement those against real backend data instead of porting the mock math.

## Design System
Built on the **Modernist** design system's structural principles (Archivo typeface, flat surfaces, thin 1px hairline borders, flush-left labels, generous spacing, 8-12px card radii) combined with a custom domain color palette (teal/amber/blue + a 5-color particle-label map) that carries QC meaning and should NOT be swapped for Modernist's red accent — the color-to-meaning mapping is a functional requirement of this product, not a brand choice.

## Screens / Views

### 1. Dashboard (`Bảng điều khiển QC`)
**Purpose:** At-a-glance shift summary + latest sample + quick nav to history.
**Layout:** Left sidebar (236px, fixed) + main content area. Content max-width 1180px, vertical flex, 20px gaps.
- **Metric tile row**: CSS grid, `repeat(auto-fit, minmax(190px,1fr))`, 14px gap. 4 tiles: "Mẫu hôm nay" (sample count), "Tổng hạt hôm nay" (total particle count), "Tỉ lệ nhựa" (plastic % in teal text), "Cảnh báo" (warning count — tile background switches to amber-bg (`#FAEEDA` light / `rgba(239,159,39,.15)` dark) when count > 0, otherwise neutral `--surface-1`). Tile padding 16px 18px, radius 8px (`--r-tile`). Value text 30px/600, label 12.5px, hint caption 11.5px `--text-3`.
- **2-column row** (`1.5fr / 1fr`, 20px gap, collapses to 1 column ≤900px): "Mẫu mới nhất" card (status chip + link to detail + backlit image + 4-row metadata list) beside "Phân bố loại" card (132px donut chart with center total label + color-swatch legend list with %).
- **Recent samples table**: last 5 today's samples, columns Mã mẫu / Mã lô / Giờ chụp / Số hạt / Trạng thái, row click opens detail. Header row 11px/500 `--text-2`.
- Collapsible "Ghi chú thiết kế" note block (`<details>`) at bottom explaining layout rationale — informational only, can be dropped in production.
- **Empty state**: icon + title + message centered card, shown when no samples loaded.

### 2. History / Audit (`Lịch sử · audit`)
**Purpose:** Dense, filterable audit log of all samples; CSV export.
**Layout:** Filter bar (from-date, to-date, lot-code select, clear-filters button, CSV export button) in a bordered card, 16px 18px padding. Below: result count summary caption, then a dense data table (min-width 820px, horizontal scroll on overflow) with columns Mã mẫu (monospace) / Mã lô / Thời gian chụp / Số hạt (right-aligned) / Phân bố loại (colored count chips per label) / Trạng thái (status chip) / row action link "Chi tiết →". Row height ~12px vertical padding, 1px top border between rows, no card-per-row. Pagination controls bottom-right (10 rows/page).
**States:** loading (shimmer skeleton rows), error (centered icon + retry button), empty (no filter matches), normal.
**Note:** No edit/delete UI anywhere — data is append-only.

### 3. Sample Detail (`Chi tiết mẫu`)
**Purpose:** Full inspection of one sample's backlit image + detected particles.
**Layout:** 2-column grid `1.35fr / 1fr` (stacks on mobile), left column sticky (`top:76px`) containing the backlit image card with SVG bbox overlays (colored per label, dashed for "unknown", labeled tag on hover) and a color legend row below. Right column (16px gap, stacked cards): metadata card (2-col key/value grid: Mã lô, Thiết bị, Giờ chụp, Giờ nhận, Hiệu chuẩn px/mm, Kích thước ảnh), particle table (Nhãn / Tin cậy / Kích thước / Diện tích / Tâm x,y — hover row ↔ hover bbox is bidirectional), size histogram (bar chart, fixed 0.3mm bins, 0–5mm range, blue bars), label distribution (horizontal bar list), and a collapsible raw metadata JSON block (monospace, `<pre>`, toggle open/closed).
**States:** loading (skeleton), error, 404/not-found (large "404" + message + "Về lịch sử" button), normal.

### 4. Stream Demo (`Stream demo`)
**Purpose:** Live canvas simulation of the backlit particle flow, for demoing the imaging concept without a live camera feed.
**Layout:** Amber demo-mode banner at top (`Chế độ demo — mô phỏng, không ghi vào lịch sử`) — always visible, explains this view is not real detection data. Below: a canvas (452px tall, light gray-green background `#C9CCC5`) rendering falling particle blobs (ellipses, gradient-shaded, bubbles get a highlight, fibers are elongated+rotated). Floating HUD (top-left, translucent blur card): live particle count + FPS; second pill shows per-label counts currently visible. Toolbar below canvas: play/pause button (teal when off / gray when playing), "Hiện detection" toggle switch (pill switch, teal when on) that overlays colored bbox+label per particle when enabled, and a speed slider (0.4×–3×).
**Pause overlay**: centered pill "Đã tạm dừng · nhấn Bật stream" when paused.

### Sidebar & Header (persistent chrome)
- Sidebar: brand mark (teal rounded-square logo) + "Aqua Scope" wordmark, 3 nav buttons (Bảng điều khiển / Lịch sử · audit / Stream demo), a "Tham chiếu" divider section with a "Trạng thái" (states gallery) link, and a footer block showing device online status dot + "aquascope-01 · trực tuyến" + a note "Dữ liệu chỉ đọc · append-only."
- Header: sticky, blurred-glass background, screen title (16.5px/600), a "LAN · demo" status pill, a "Xem trạng thái" state-simulator dropdown (dashboard/history/detail only — dev/QA tool, can be dropped in production or kept behind a feature flag), dark-mode toggle (persisted), "Xuất CSV" primary teal button.
- Toast: bottom-center floating confirmation (e.g. after CSV export), auto-dismiss ~2.6s.

## Interactions & Behavior
- Client-side view switching (dashboard/history/detail/stream/states-gallery) — no page reload.
- Dark mode: toggle in header, persisted to localStorage, applied via a `data-theme="dark"` attribute that swaps all CSS custom properties (0.22s color-transition).
- History filters (date range + lot) are client-applied and reset pagination to page 1 on change; "Xuất CSV" always exports according to the currently active filter.
- Sample detail image ↔ particle table hover is bidirectional (hovering a table row highlights its bbox on the image and vice versa).
- Raw JSON panel is collapsed by default; toggle button flips an open/closed state.
- Stream demo runs a `requestAnimationFrame` loop; play/pause toggles the loop, speed slider scales fall speed and spawn rate, "Hiện detection" toggle overlays bbox+label per particle without affecting the underlying simulation.
- "Xem trạng thái" dropdown (dashboard/history/detail) is a design/QA affordance to preview empty/loading/error/404 states without real data — decide with your team whether to ship it (e.g. behind a debug flag) or drop it.

## State Management
Per-screen states needed for real implementation:
- Dashboard: `normal`, `empty` (no samples loaded)
- History: `normal`, `empty` (filters match nothing), `loading`, `error`
- Detail: `normal`, `notfound` (404 / invalid sample id), `loading`, `error`
- Filters: `fromDate`, `toDate`, `lotCode`, `page` (History)
- Detail: `sampleId` (route param), `jsonOpen` (bool), `hoveredParticleIndex`
- Stream: `playing` (bool), `showDetections` (bool), `speed` (0.4–3.0)
- Global: `theme` (light/dark, persisted), `toast` (transient message)

**Data fetching requirements for production:** samples list (paginated, filterable by date range + lot code), single sample detail (metadata + particle detections + backlit image URL), CSV export endpoint respecting active filters, and — for the stream view — either a live MJPEG/WebSocket feed from the device or an explicit "demo mode" flag so it's never confused with a real audit record.

## Design Tokens

**Color** (light / dark):
- Background: `--bg` `#F4F5F3` / `#0F1214`
- Surface: `--surface` `#FFFFFF` / `#171B1E`; `--surface-1` `#F0F1EE` / `#1E2327` (tile fill, table header); `--surface-2` `#E9EAE6` / `#262C31` (hover/skeleton)
- Border: `--border` `rgba(24,26,22,.10)` / `rgba(255,255,255,.09)`; `--border-strong` `rgba(24,26,22,.18)` / `rgba(255,255,255,.18)`
- Text: `--text` `#1B1D19` / `#E7E9E6`; `--text-2` `#5C5E58` / `#A7ABA4`; `--text-3` `#8A8C84` / `#797E77`
- Teal (brand / "Đạt" pass status): `--teal` `#1D9E75` / `#2FB88A`; `--teal-strong` `#0F6E56` / `#7FE0BD`; `--teal-bg` `#E1F5EE` / `rgba(29,158,117,.16)`; `--teal-text` `#0F6E56` / `#5FD3A6`
- Amber (backlit / "Cảnh báo" warning status): `--amber` `#EF9F27` / `#F3B24D`; `--amber-strong` `#854F0B` / `#F8CB80`; `--amber-bg` `#FAEEDA` / `rgba(239,159,39,.15)`; `--amber-text` `#854F0B` / `#F3B24D`
- Blue (info / histogram bars): `--blue` `#378ADD` / `#5AA2E8`; `--blue-bg` `#E8F1FC` / `rgba(55,138,221,.16)`; `--blue-text` `#1E5FA8` / `#84B8EF`
- Gray (neutral): `--gray` `#888780` / `#9A998F`
- **Particle label colors** (used consistently across bbox overlay, charts, chips — do not deviate): plastic `--p-plastic` = teal; bubble `--p-bubble` = blue; organic `--p-organic` = amber; fiber `--p-fiber` = gray (`#888780`/`#9A998F`); unknown `--p-unknown` = `#B4B2A9` (both modes, dashed outline in bbox)

**Radius:** `--r-card` 12px (cards), `--r-tile` 8px (metric tiles), `--r-chip` 999px (status chips/pills)

**Shadow:** `--shadow`: `0 1px 2px rgba(24,26,22,.05)` light / `0 1px 2px rgba(0,0,0,.4)` dark (cards only — flat otherwise, no heavy elevation)

**Typography:** Archivo (400/500/600), loaded via Google Fonts. Scale: 30px/600 (metric values), 16.5px/600 (page title), 14–14.5px/600 (card headings), 13px/400 (body), 12–12.5px (table/meta text), 11–11.5px (captions/labels), 10–10.5px (micro labels/section eyebrows). Monospace (`ui-monospace, Menlo, monospace`) for sample codes, lot codes, JSON, centroid coordinates.

**Spacing:** page padding 26px top / 28px sides; card padding 16-18px; grid gaps 14–20px; row vertical padding ~9-12px.

**Borders:** 1px hairlines throughout (`--border`), not the heavier rules Modernist uses on its own pages — this product prioritizes dense tabular scanning over poster-style structure.

## Assets
- **Brand mark**: small inline SVG (teal rounded-square with a ring + two dots) — replace with the real Aqua Scope logo if one exists.
- **Icons**: minimal inline SVG line icons (grid, list, wave, layers, download, check, warning-triangle, sun/moon), 16–30px, stroke-based, 1.5–1.8px stroke width, rounded caps/joins. Recreate with your codebase's icon set (e.g. Lucide) at equivalent weights.
- **Backlit particle images**: synthetic — a soft gray-green radial-gradient field (`#E4E6E1` → `#C9CCC5`) with dark soft-edged ellipse "blobs" per particle (bubbles get a light-gray ring + highlight; fibers are elongated and rotated). This stands in for the real device's backlit photograph. In production, swap for the actual captured image with detection bboxes drawn as an overlay (SVG/canvas) at the same coordinate scale (14 px/mm calibration, 640×480 source resolution).
- **Charts**: donut (dashboard) and bar histogram (detail) are hand-built inline SVG, not a charting library — recreate with your codebase's chart component of choice using the same color mapping and proportions.

## Files
- `Aqua Scope QC.dc.html` — full design reference (all 4 screens + states gallery + chrome), inline-styled, React-class-component-style logic embedded in the file.
- `support.js` — runtime helper the reference file depends on to render (not application logic to port).

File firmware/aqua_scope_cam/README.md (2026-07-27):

# Aqua Scope Cam — Firmware

> **Tham khảo/thử nghiệm — không nạp bản này.** Firmware chính thức của dự án
> là [`firmware/aqua_scope_station/`](../aqua_scope_station/).

Firmware camera tùy chỉnh cho **XIAO ESP32-S3 Sense** (cảm biến **OV3660**, 3MP), thay cho firmware
Matchboxscope (vốn dành cho kính hiển vi). Tối ưu cho **ảnh backlit silhouette**:
nền sáng đều, hạt rác 1–5mm hiện lên thành **bóng đen** để đếm & đo kích thước.

## Vì sao không dùng firmware Matchboxscope?

Firmware Matchboxscope để auto-exposure và tối ưu cho vật soi gần dưới kính hiển
vi. Với đèn nền (backlight) của ta, auto-exposure sẽ **kéo nền cháy trắng** và mất
hạt. Firmware này **ép phơi sáng thủ công** và **lưu cứng** thông số vào flash.

## Tính năng

- **Ép phơi sáng thủ công**: TẮT AEC / AEC-DSP / AGC; đặt Gain=0 + Exposure thấp
  → nền không cháy trắng (đúng theo `CLAUDE.md`).
- **Lưu cứng cấu hình** vào flash (NVS/`Preferences`): cắm điện là chạy đúng thông
  số đã chỉnh, không phải canh lại mỗi lần.
- **Chọn độ phân giải tự do**: một dropdown QVGA→QXGA (dùng chung cho stream và
  chụp), đổi ngay khi test để so sánh — không khóa cứng vào 2 chế độ.
- Chỉnh qua **Web UI** (slider trực quan) **hoặc Serial**.
- Có sẵn **hook `runVision()`** để nhúng computer vision on-device về sau.

## Cài đặt (Arduino IDE)

1. Cài **Arduino IDE** + gói board **esp32 by Espressif** (Boards Manager, ≥ 3.0).
2. Mở `aqua_scope_cam.ino` (giữ nguyên `camera_pins.h` cùng thư mục).
3. Trong **Tools**:
   - Board: **XIAO_ESP32S3**
   - **PSRAM: OPI PSRAM**  ← *bắt buộc*, không bật thì camera không init được
   - Partition Scheme: **Huge APP (3MB No OTA/1MB SPIFFS)**
4. Cắm board qua USB-C, chọn đúng Port, bấm **Upload**.
   - Nếu upload lỗi: giữ nút **BOOT** khi cắm để vào bootloader.

## Cách dùng

### Qua WiFi (khuyến nghị — canh sáng bằng mắt)
1. Mặc định board phát WiFi **`AquaScope`** (mật khẩu `aquascope`).
2. Nối điện thoại/laptop vào WiFi đó → mở trình duyệt tới **http://192.168.4.1**
3. Bật đèn nền, kéo slider **Exposure/Gain** đến khi nền **xám đều**, hạt = **bóng
   đen rõ nét** (không có đốm sáng chói, camera không thấy đèn LED trần).
4. Chọn **Độ phân giải** trong dropdown (QVGA→QXGA) để so sánh khi test; bấm
   **Chụp 1 ảnh** để xem ảnh ở đúng độ phân giải đang chọn.
5. Ưng ý → bấm **LƯU CỨNG vào flash**. Lần sau cắm điện tự chạy đúng thông số
   (kể cả độ phân giải đã chọn).
6. Lỡ chỉnh nhầm → bấm **Khôi phục mặc định** (có hỏi xác nhận): mọi thông số về
   giá trị gốc và cấu hình đã lưu trong flash bị xóa, giao diện tự làm mới.

> Muốn nối vào router nhà thay vì AP: sửa `USE_STA = true` và điền `STA_SSID/STA_PASS`.

### Qua Serial (115200 baud)
| Lệnh | Ý nghĩa |
|---|---|
| `t100` | đặt exposure = 100 |
| `g0` | đặt gain = 0 |
| `b0` / `c1` | brightness / contrast |
| `q12`  | JPEG quality |
| `y1` | grayscale on (0 = màu) |
| `f12`  | đổi độ phân giải (5=QVGA, 8=VGA, 9=SVGA, 10=XGA, 12=SXGA, 13=UXGA, 17=QXGA) |
| `p` | in cấu hình hiện tại |
| `s` | **lưu cứng** vào flash |
| `r` | **khôi phục mặc định** (về giá trị gốc + xóa cấu hình đã lưu) |
| `x` | chụp 1 frame analysis (chạy `runVision`) |

### Endpoint HTTP (để PC lấy ảnh chạy CV)
- `GET /stream`  — MJPEG preview (ở độ phân giải đang chọn)
- `GET /capture` — chụp **1 ảnh JPEG** ở độ phân giải hiện tại (đây là ảnh để chạy CV)
- `GET /control?var=framesize&val=12` — đổi độ phân giải (giá trị enum như bảng serial)
- `GET /control?var=exposure&val=100` — chỉnh runtime
- `GET /control?var=save&val=1` — lưu cứng
- `GET /control?var=reset&val=1` — khôi phục mặc định + xóa cấu hình đã lưu
- `GET /status`  — JSON cấu hình

## Firmware có ảnh hưởng tới computer vision sau này không?

**Có — theo hướng tích cực, và có hai đường đi:**

**Đường A — CV chạy trên PC (dễ, nên làm trước):**
Firmware này đã phục vụ sẵn `GET /capture` trả ảnh **SXGA JPEG chất lượng cao**.
Script Python/OpenCV trên máy tính chỉ việc `requests.get(".../capture")` → threshold
→ `connectedComponentsWithStats` → đếm + đo diện tích hạt. **Không cần sửa firmware.**

**Đường B — CV chạy on-device trên ESP32-S3 (đúng mục tiêu cuối trong `CLAUDE.md`):**
Có sẵn hàm `runVision(camera_fb_t* fb)` — mỗi lần chụp analysis firmware gọi hàm này.
Chỉ cần điền phần xử lý vào đó. Vài lưu ý firmware giúp việc này:
- Ảnh đã ép **grayscale** (`grayscale=1`) → threshold trực tiếp, đỡ 1 bước.
- Frame trả về là **JPEG**; để làm CV trên chip cần **giải nén sang buffer thô**
  bằng `jpg2rgb565`/`fmt2rgb888` (có trong `esp32-camera`) hoặc chuyển
  `pixel_format` sang `PIXFORMAT_GRAYSCALE` khi chụp analysis.
- **PSRAM** (đã bật) là chỗ chứa buffer ảnh lớn để chạy connected-components — đây
  là lý do bật OPI PSRAM là bắt buộc.

Tóm lại: firmware này **được thiết kế để không chặn CV** — hook và endpoint đã có,
độ phân giải analysis đủ cao (~14 px/mm ở 40mm), ảnh xám sẵn sàng. Firmware
Matchboxscope thì ngược lại: auto-exposure của nó sẽ phá dữ liệu đầu vào của CV.

## Quản lý nhiệt & nguồn — PROTOTYPE (chưa nhúng vào `.ino`)

> **Trạng thái:** đây là *bản phác thảo phần mềm*, chưa có trong `aqua_scope_cam.ino`.
> Firmware hiện tại chạy **stream MJPEG liên tục** (port 81) + WiFi luôn bật → đây
> chính là nguyên nhân **board nóng và có thể sập** khi vận hành lâu. Mục này gom
> các cách khắc phục **thuần phần mềm** để triển khai ở bước sau.

### Chẩn đoán gốc rễ
| Nguồn nhiệt/tải | Mức | Vì sao |
|---|---|---|
| WiFi radio phát liên tục (stream) | 🔴 lớn nhất | dòng đỉnh 300–500mA, sinh nhiệt nhiều nhất trên board |
| Camera grab frame không nghỉ (vòng `while` trong `stream_handler`) | 🟠 vừa | XCLK 20MHz + DMA + JPEG encoder chạy liên tục |
| CPU 240MHz + nhiệt bị nhốt trong ống Imaging Tube kín | 🟡 | ống đục kín chặn sáng cũng nhốt nhiệt |

> "Sập" thường là **brownout** (WiFi TX + capture cùng lúc làm sụt 3.3V → reset),
> chứ không phải nhiệt trực tiếp. Fix phần cứng (tụ bulk + nguồn 5V ≥2A) nằm ngoài
> phạm vi mục này; ở đây chỉ xử lý phần mềm.

### Ý tưởng cốt lõi: bám chu trình Stop-Flow, KHÔNG stream liên tục
Vận hành thật chỉ cần **1 ảnh/chu kỳ** (lúc nước đứng yên). Giữa các chu kỳ là thời
gian nghỉ để hạ nhiệt. Chuyển từ "stream mãi mãi" sang **máy trạng thái duty-cycle**:

```cpp
// PROTOTYPE — máy trạng thái Stop-Flow thay cho stream liên tục
enum Phase { FILLING, SETTLING, CAPTURING, DRAINING, COOLDOWN };
Phase phase = FILLING;
uint32_t tPhase = 0;
bool streamOnDemand = false;   // stream CHỈ bật khi đang canh sáng qua web

void loopCycle() {
  handleSerial();
  uint32_t now = millis();
  switch (phase) {
    case SETTLING:                       // nước đã đứng yên
      if (now - tPhase > 1500) {         // chờ lắng 1.5s
        camera_fb_t* fb = esp_camera_fb_get();   // <-- CHỤP ĐÚNG 1 FRAME
        if (fb) { runVision(fb); esp_camera_fb_return(fb); }
        phase = DRAINING; tPhase = now;
      }
      break;
    case COOLDOWN:                       // nghỉ giữa chu kỳ: đây là lúc hạ nhiệt
      if (now - tPhase > COOLDOWN_MS) { phase = FILLING; tPhase = now; }
      break;
    // ... FILLING / CAPTURING / DRAINING điều khiển bơm & van
  }
}
```

### Các đòn bẩy phần mềm (xếp theo hiệu quả)
1. **Tắt stream ở chế độ production.** Chỉ chạy `stream_handler` khi `streamOnDemand`
   bật (lúc canh sáng); vận hành thật thì **không đăng ký server port 81**, hoặc dừng
   nó sau khi đã lưu cấu hình. Đây là đòn giảm nhiệt lớn nhất.
2. **WiFi modem-sleep / tắt giữa chu kỳ.**
   ```cpp
   WiFi.setSleep(WIFI_PS_MAX_MODEM);        // luôn cho radio ngủ khi rảnh
   // hoặc quyết liệt hơn: WiFi.mode(WIFI_OFF) ở COOLDOWN, bật lại + gửi kết quả rồi tắt
   WiFi.setTxPower(WIFI_POWER_11dBm);        // hạ công suất phát nếu router/điện thoại ở gần
   ```
   Vì CV chạy on-device chỉ xuất **con số đếm + phân bố kích thước** (vài chục byte),
   WiFi chỉ cần bật burst ngắn mỗi chu kỳ — hoặc bỏ hẳn, gửi qua Serial/USB.
3. **Hạ XCLK 20MHz → 10MHz** trong `initCamera()` (`c.xclk_freq_hz = 10000000;`) —
   giảm nhiệt sensor rõ, đổi lại chụp chậm hơn chút (chấp nhận được với Stop-Flow).
4. **Giữ camera đã init, chỉ grab khi cần** — KHÔNG `esp_camera_deinit()/init()` lặp
   mỗi vòng (reinit chậm + phải ổn định lại sensor). Camera idle giữa các lần chụp.
5. **Giám sát nhiệt nội + thermal throttle** (ESP32-S3 có cảm biến nhiệt on-chip):
   ```cpp
   #include "driver/temperature_sensor.h"
   // nếu t > ~75°C thì kéo dài COOLDOWN_MS / bỏ 1 chu kỳ cho hạ nhiệt
   ```
6. **Task Watchdog để tự phục hồi khi treo** (`esp_task_wdt_init()` + `..._reset()`
   trong vòng lặp) → treo thì reset lại thay vì đơ cứng.
7. **Xử lý `esp_camera_fb_get()` trả NULL có kiểm soát** (retry giới hạn) để một lần
   chụp lỗi không làm kẹt vòng lặp — hiện `stream_handler` gặp NULL là `break` cả stream.

### Ranh giới phạm vi
- **Phần mềm (mục này):** duty-cycle, tắt stream, WiFi sleep, XCLK, throttle, watchdog.
- **Phần cứng (làm riêng, không thuộc firmware):** tụ bulk 470–1000µF, nguồn 5V ≥2A,
  heatsink lên chip, **lỗ thông gió bẫy-sáng ở top cap** (sẽ thêm hằng số vào OpenSCAD).

## Thông số mặc định (chỉnh trong `.ino`, biến `cfg`)

| Tham số | Mặc định | Ghi chú |
|---|---|---|
| exposure | 100 | slider chính, tăng nếu ảnh tối |
| gain | 0 | backlit nên để 0 |
| contrast | 1 | tách bóng hạt |
| grayscale | 1 | 1 = xám (tốt cho CV) |
| framesize | VGA (640×480) | độ phân giải dùng chung, đổi tự do tới **QXGA 2048×1536** khi test |
| vflip | 1 | OV3660 mặc định ảnh lật ngược → để 1 cho đúng chiều |

## Ghi chú riêng cho OV3660 (khác OV2640)

- OV3660 là **3MP**, phân giải tối đa **QXGA 2048×1536** (OV2640 chỉ UXGA 1600×1200).
  Buffer camera đã cấp phát ở QXGA nên dropdown có thể chọn lên tới QXGA để đo
  hạt 1mm nét hơn (đổi lại CV nặng hơn, RAM/thời gian nhiều hơn).
- Driver `esp32-camera` **tự nhận diện** OV3660 qua SCCB — không cần đổi code init.
- OV3660 trả ảnh **lật ngược mặc định**, nên firmware để `vflip=1`. Với đếm hạt thì
  chiều ảnh không ảnh hưởng kết quả CV, nhưng để đúng chiều khi xem preview.

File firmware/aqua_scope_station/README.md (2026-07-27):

# Aqua Scope — Firmware chính thức (ESP32-CAM AI-Thinker)

**Đây là bản duy nhất cần nạp.** Các thư mục firmware khác trong repo là thử
nghiệm hoặc tiền đề, giữ lại để tham khảo:

| Thư mục | Là gì |
|---|---|
| `firmware/Esp32 cam/` | thử nghiệm ban đầu — không nạp |
| `firmware/aqua_scope_cam/` | tiền đề — không nạp |
| `firmware/esp32-cam-webserver/` | **repo git lồng** (bản port easytarget, đang sửa dở). Không phải firmware của trạm. Vì là repo riêng nên không đặt ghi chú vào README của nó — ghi ở đây thay thế |
| `firmware/pump_stopflow_test/` | công cụ test bơm độc lập, vẫn dùng được — không phải firmware của trạm |
| `dataset_collector/firmware/` | bản tiền thân trực tiếp của thư mục này. `collect_dataset.py` chạy được với cả hai vì cùng `/capture` |

Vai trò: cung cấp ảnh backlit chất lượng đúng, ổn định, kèm đủ thông tin để
truy xuất nguồn gốc. Firmware **không** đếm hạt, không lưu trữ, không suy luận
— việc đó do `ml.infer` trên máy tính làm.

## Endpoint

| Endpoint | Dùng để |
|---|---|
| `GET /` | Web UI canh sáng (slider) |
| `GET /stream` | MJPEG xem trực tiếp — chỉ dùng lúc canh sáng |
| `GET /capture` | Một ảnh JPEG. Chụp lỗi → **503** kèm lý do |
| `GET /device` | JSON danh tính + thiết lập camera (khối audit) |
| mDNS `aqua-scope.local` | Board tự xưng tên trong LAN — khỏi mở Serial Monitor lấy IP |
| `GET /status` | JSON cấu hình cho slider (bản gốc Espressif) |
| `GET /control?var=darkmode&val=1` | **Bật preset buồng tối backlit** (tắt AEC/AEC-DSP/AGC, gain 0, exposure 200, contrast +2, …) — chạy trước khi chụp khung phân tích |
| `GET /control?var=save&val=1` | Ghi cứng cấu hình camera + bơm vào flash |
| `GET /control?var=reset&val=1` | Xóa cấu hình đã lưu, về mặc định auto exposure (như bản gốc) + reset pump |
| `GET /control?var=device_id&val=<tên>` | Đổi device_id (khớp `[A-Za-z0-9._-]`, 1–64 ký tự) |
| `GET /control?var=pump_auto&val=1` | Bật chu trình Stop-Flow tự động |
| `GET /control?var=pump_auto&val=0` | Tắt chu trình (ramp bơm xuống 0) |
| `GET /control?var=pump_fill_ms&val=5000` | Thời gian pha FILLING (ms) |
| `GET /control?var=pump_settle_ms&val=2000` | Thời gian pha SETTLING (ms) |
| `GET /control?var=pump_flush_ms&val=5000` | Thời gian pha FLUSHING (ms) |
| `GET /control?var=pump_cooldown_ms&val=3000` | Thời gian pha COOLDOWN (ms) |
| `GET /control?var=pump_fill_duty&val=55` | Duty % pha FILL (0–100) |
| `GET /control?var=pump_flush_duty&val=100` | Duty % pha FLUSH (0–100) |
| `GET /control?var=pump_ramp_up_ms&val=250` | Thời gian ramp lên (ms) |
| `GET /control?var=pump_ramp_down_ms&val=350` | Thời gian ramp xuống (ms) |

## Đấu nối bơm L298N

```
ESP32-CAM GPIO13 ──→ L298N ENA (PWM 20kHz/10-bit)
L298N IN1         ──→ 3.3V (cố định)
L298N IN2         ──→ GND  (cố định, một chiều)
L298N +12V        ──→ Adapter 12V/2A riêng
L298N GND         ──→ GND chung với ESP32-CAM
L298N OUT1/OUT2   ──→ Bơm RS365 12V
Tụ gốm 0.1µF hàn ngang 2 cực bơm (chống nhiễu chổi than)
```

> **An toàn:** `autoRunning` mặc định **TẮT** lúc cấp điện — phải bật tay qua
> `?var=pump_auto&val=1` (HTTP) hoặc `a` (Serial).
>
> GPIO13 được ép LOW ở **dòng đầu tiên của `setup()`**, trước cả `Serial.begin()`.
> Ép muộn hơn là để hở một cửa sổ dài: giữa lúc cấp điện và lúc gắn PWM còn có
> camera init + WiFi connect (timeout tới 20s) và cả nhánh restart khi camera
> lỗi — thừa thời gian để một chân ENA thả nổi (L298N đọc là HIGH) làm tràn khay.
>
> Nếu `ledcAttach` thất bại, firmware **báo lỗi ra Serial và `/device` trả
> `pump.pwm_ready: false`** thay vì im lặng nhận lệnh mà bơm không nhúc nhích.

## Serial commands (bơm)

Gõ trong Serial Monitor 115200, mỗi lệnh 1 ký tự:

| Lệnh | Ý nghĩa |
|---|---|
| `p` | In trạng thái bơm |
| `0` | Manual OFF (ramp xuống 0, tắt auto) |
| `1` | Manual ON (ramp lên fillDuty, tắt auto) |
| `a` | Bật auto Stop-Flow từ FILLING |
| `f<ms>` | Đặt fill time, vd `f3000` |
| `s<ms>` | Đặt settle time, vd `s1500` |
| `x<ms>` | Đặt flush time, vd `x8000` |
| `c<ms>` | Đặt cooldown time, vd `c5000` |
| `u<ms>` | Ramp UP time, vd `u250` |
| `w<ms>` | Ramp DOWN time, vd `w350` |
| `d<0-100>` | CRUISE duty pha FILL, vd `d45` |
| `X<0-100>` | Duty pha FLUSH, vd `X100` |
| `r` | Reset timing về mặc định |
| `?` | In menu lệnh |

## Nạp firmware

Arduino IDE, cần gói board **esp32 by Espressif ≥ 3.0**:

| Mục | Chọn |
|---|---|
| Board | **AI Thinker ESP32-CAM** |
| Partition Scheme | **Huge APP (3MB No OTA/1MB SPIFFS)** |

Sửa WiFi ở đầu `aqua_scope_station.ino`, nối **IO0 → GND**, cấp nguồn, Upload,
rút IO0, reset. Mở Serial Monitor 115200 để lấy IP và `device_id`.

## Khác gì bản CameraWebServer gốc

> **Phơi sáng mặc định: GIỐNG bản gốc (auto).** Bản trước ép tắt
> AEC/AEC-DSP/AGC + exposure 100 ngay lúc boot và mỗi lần `?var=reset`, nên ảnh
> mặc định tối và khó ngắm/chỉnh — đã bỏ. Cấp điện lần đầu là ảnh sáng bình
> thường.
>
> Nhưng **canh sáng backlit vẫn bắt buộc trước khi chụp khung phân tích** —
> chụp đo ở chế độ auto thì nền cháy trắng và nuốt mất hạt. Không phải kéo tay
> từng slider: gọi **một lệnh**
>
> ```
> curl "http://<ip>/control?var=darkmode&val=1"
> ```
>
> (port từ `?var=darkmode` của `dataset_collector` — bộ thông số đã canh trên
> chính rig này), tinh chỉnh thêm bằng slider Exposure nếu cần, rồi `?var=save`.
> Đã `save` một lần thì các lần boot sau nạp lại đúng cấu hình đó, mặc định auto
> không ghi đè. Muốn về lại auto: `?var=reset` (lưu ý reset xoá cả cấu hình bơm).

1. **Không bật đèn flash khi chụp.** Bản gốc bật GPIO4 150ms trước mỗi lần
   chụp. Rig này chiếu sáng **từ dưới** — thêm đèn từ trên làm nhạt bóng hạt
   và tạo phản xạ trên mặt nước.
2. **Mặc định UXGA 1600×1200** — hạt <2mm cần độ phân giải.
3. **Lưu cấu hình vào flash** — `?var=save` / `?var=reset` (lưu cả camera lẫn bơm).
4. **`/device`** — device_id sinh từ MAC + thiết lập camera + trạng thái bơm.
5. **Chạy dài không chết** — tự nối lại WiFi, watchdog, chụp lỗi trả 503.
   `loop()` nghỉ 50ms mỗi vòng (thay vì 10×1s) để pump tick phản hồi kịp thời.
6. **Điều khiển bơm L298N** — state machine Stop-Flow (FILLING/SETTLING/FLUSHING/
   COOLDOWN) với PWM ramp chống búa nước, điều khiển qua HTTP và Serial.

## mDNS — khỏi đi tìm IP

Board tự xưng `aqua-scope.local` sau khi nối WiFi (và tự xưng lại sau mỗi lần
nối lại). Dashboard web thử tên này trước khi bắt bạn gõ IP.

```
curl http://aqua-scope.local/device
```

**Không phải mạng nào cũng cho.** Một số router chặn multicast, mạng khách bật
AP isolation, vài máy Windows cũ thiếu bộ phân giải .local. Ô nhập IP tay trên
dashboard là đường dự phòng chính thức — không phải tính năng thừa. Chế độ
`USE_AP` không bật mDNS — nối thẳng vào board tại `http://192.168.4.1`.

## Checklist nghiệm thu trên board thật

Chưa chạy đủ các mục này thì **chưa được nói firmware "chạy được"**.

- [ ] 1. Nạp xong, Serial 115200 in ra IP và `device_id = aqua-cam-xxxxxx`
- [ ] 2. `curl http://<ip>/device` → JSON hợp lệ, `psram: true`, có object `pump`
- [ ] 3. Mở `http://<ip>/` chỉnh slider → nền xám đều, hạt là bóng đen rõ
- [ ] 3a. Cấp điện lần đầu (chưa từng `?var=save`) → mở `http://<ip>/` → ảnh
      **sáng bình thường**, không phải mảng xám tối; slider AEC/AGC ở trạng thái ON
- [ ] 3b. `?var=reset` khi đang ở cấu hình đã lưu → về đúng trạng thái auto ở
      mục 3a (không quay lại mặc định dark cũ)
- [ ] 3c. `?var=darkmode&val=1` → Serial in `[cam] Da ap preset buong toi`, ảnh
      chuyển sang nền sáng đều + hạt là bóng đen; `?var=reset` → về lại auto
- [ ] 4. Tắt AEC/AGC + chỉnh tay theo quy trình canh sáng backlit → `?var=save`
      → rút điện → cắm lại → `/device` báo `prefs_saved: true` và đúng thông số
      camera + bơm vừa chỉnh (mặc định auto **không** ghi đè)
- [ ] 5. Tắt router 30 giây rồi bật lại → board tự nối lại, `/device` phản hồi,
      **không** cần bấm reset
- [ ] 6. `python -m ml.infer --from-board <ip> --count 3 --dry-run` → 3 khung,
      không có dòng nào ghi vào DB
- [ ] 7. Bỏ `--dry-run` → 3 mẫu hiện trên dashboard, cột device_id đúng tên board
- [ ] 8. Serial in `[pump] init OK`, `/device` báo `pump.pwm_ready: true`
- [ ] 9. Cấp điện, **chưa gõ lệnh nào** → bơm đứng im hoàn toàn (kể cả trong
      lúc board đang dò WiFi). Đây là mục kiểm tra chân ENA không thả nổi.
- [ ] 10. Serial gõ `a` → bơm chạy chu trình, `p` → in đúng trạng thái pha
- [ ] 11. `?var=pump_auto&val=1` → bơm bắt đầu, `/device` báo `pump.auto: true`
- [ ] 12. `?var=pump_fill_duty&val=150` → trả **HTTP 500** (không phải 200)
- [ ] 13. `?var=save` → rút điện → cắm lại → `/device` báo đúng timing bơm đã lưu
- [ ] 14. Serial in `[mdns] http://aqua-scope.local` sau dòng `WiFi OK`
- [ ] 15. Tắt router 30 giây rồi bật lại → sau khi board tự nối lại,
      `curl http://aqua-scope.local/device` **vẫn** trả JSON (mDNS được bật lại,
      không chết theo lần rớt mạng)

## Chưa có (cố ý)

Điều khiển đèn nền (đèn cắm thẳng, luôn sáng), suy luận on-device, tự động
chụp ảnh theo pha SETTLING (script PC chủ động pull `/capture`, trường
`pump.phase` trong `/device` là thông tin để script tự biết lúc nào là SETTLING
nếu sau này muốn tự động hoá — nằm ngoài phạm vi firmware).

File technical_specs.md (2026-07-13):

# Thông số kỹ thuật các cấu phần 3D (3D Models Technical Specifications)
Tài liệu này tổng hợp các thông số kỹ thuật được trích xuất trực tiếp từ hình học của các tệp STL trong thư mục `base/` và `perestaltic pump/` phục vụ cho việc xây dựng mô hình OpenSCAD.
--- 
## 📁 Thư mục: `base`
### 📄 Tệp: `Assembly_Matchboxscope_injectionmolded_xiao_IM_Matchboxscope_base_xiao_9.stl`
- **Kích thước hộp bao (Bounding Box)**: 50.45 mm (X) x 52.00 mm (Y) x 12.00 mm (Z)
- **Thể tích (Volume)**: 16034.57 mm³
- **Diện tích bề mặt (Surface Area)**: 7783.16 mm²
- **Vật thể kín (Is Closed Manifold)**: Có (Watertight)
- **Các tính năng hình học phát hiện được**:
  * **Mặt cắt vuông góc trục Z**:
    * Đường kính ~ **1.3 mm** (Bán kính 0.7 mm) tại các tâm: `[8.8, 66.5, -42.5]`
    * Đường kính ~ **2.8 mm** (Bán kính 1.4 mm) tại các tâm: `[2.2, 89.5, -45.7]; [-14.5, 73.5, -45.7]; [-14.5, 73.5, -44.9]; [2.2, 89.5, -44.9]; [-14.5, 73.5, -44.1]; [2.2, 89.5, -44.1]; [-14.5, 73.5, -43.3]; [-14.5, 73.5, -42.5]; [-14.5, 73.5, -41.7]; [8.8, 66.5, -41.7]; [8.8, 66.5, -40.8]; [8.8, 96.5, -40.8]; [-21.2, 66.5, -40.8]; [8.8, 96.5, -40.0]; [-21.2, 66.5, -40.0]; [8.8, 66.5, -40.0]; [8.8, 66.5, -39.2]; [8.8, 96.5, -39.2]; [-21.2, 66.5, -39.2]; [8.8, 96.5, -38.4]; [-21.2, 66.5, -38.4]; [8.8, 66.5, -38.4]; [8.8, 96.5, -37.6]; [-21.2, 66.5, -37.6]; [8.8, 66.5, -37.6]; [8.8, 96.5, -36.8]; [-21.2, 66.5, -36.8]; [8.8, 66.5, -36.8]; [8.8, 96.5, -36.0]; [-21.2, 66.5, -36.0]; [8.8, 66.5, -36.0]; [8.8, 96.5, -35.1]; [-21.2, 66.5, -35.1]; [8.8, 66.5, -35.1]; [8.8, 96.5, -34.3]; [-21.2, 66.5, -34.3]; [8.8, 66.5, -34.3]`
    * Đường kính ~ **4.0 mm** (Bán kính 2.0 mm) tại các tâm: `[16.6, 74.4, -45.7]; [16.6, 81.9, -45.7]; [-22.5, 98.6, -45.7]; [-0.0, 58.5, -45.7]; [16.6, 81.9, -44.9]; [16.6, 74.4, -44.9]; [-22.5, 98.6, -44.9]; [-0.0, 58.5, -44.9]; [-0.0, 58.5, -44.1]; [16.6, 74.4, -44.1]; [16.6, 81.9, -44.1]; [-22.5, 98.6, -44.1]; [16.6, 81.9, -43.3]; [16.6, 74.4, -43.3]; [-22.5, 98.6, -43.3]; [-0.0, 58.5, -43.3]; [16.6, 74.4, -42.5]; [16.6, 81.9, -42.5]; [-0.0, 58.5, -42.5]; [16.6, 74.4, -41.7]; [16.6, 81.9, -41.7]; [-0.0, 58.5, -41.7]; [16.6, 74.4, -40.8]; [-0.0, 58.5, -40.8]; [16.6, 74.4, -40.0]; [-0.0, 58.5, -40.0]; [16.6, 74.4, -39.2]; [-0.0, 58.5, -39.2]; [16.6, 74.4, -38.4]; [-0.0, 58.5, -38.4]; [16.6, 74.4, -37.6]; [-0.0, 58.5, -37.6]; [16.6, 74.4, -36.8]; [-0.0, 58.5, -36.8]; [-0.0, 58.5, -36.0]; [16.6, 74.4, -36.0]; [16.6, 74.4, -35.1]; [-0.0, 58.5, -35.1]; [16.6, 74.4, -34.3]; [-0.0, 58.5, -34.3]`
    * Đường kính ~ **5.7 mm** (Bán kính 2.9 mm) tại các tâm: `[16.6, 81.9, -45.7]; [16.6, 81.9, -44.9]; [16.6, 81.9, -44.1]; [16.6, 81.9, -43.3]; [16.6, 81.9, -42.5]; [16.6, 81.9, -41.7]`
    * Đường kính ~ **7.5 mm** (Bán kính 3.8 mm) tại các tâm: `[-6.2, 81.5, -44.9]`
    * Đường kính ~ **7.9 mm** (Bán kính 4.0 mm) tại các tâm: `[-6.2, 81.5, -45.7]`
    * Đường kính ~ **8.0 mm** (Bán kính 4.0 mm) tại các tâm: `[7.2, 95.1, -45.7]; [-15.7, 92.5, -45.7]; [-19.6, 68.1, -45.7]; [7.2, 95.1, -44.9]; [-19.6, 68.1, -44.9]; [-15.7, 92.5, -44.9]; [7.2, 95.1, -44.1]; [-15.7, 92.5, -44.1]; [-19.6, 68.1, -44.1]; [-19.6, 68.1, -43.3]; [-15.7, 92.5, -43.3]; [-19.6, 68.1, -42.5]; [-15.7, 92.5, -42.5]; [-15.7, 92.5, -41.7]; [-19.6, 68.1, -41.7]`
  * **Độ dày / Khoảng cách phẳng trên trục Z**: 1.0 mm, 3.1 mm

#### 🔩 Diễn giải giao diện lắp ghép (kiểm định lại độc lập bằng `trimesh`, 2026-07-07)
Cắt lát cross-section nhiều mức Z (rstd < 0.02 → lỗ tròn thật). Phân loại các lỗ theo chức năng:

| Cụm lỗ | Vị trí (tâm) | Ø đo được | Chức năng | Dùng khi dựng SCAD? |
|---|---|---|---|---|
| **4 lỗ ốc M3** (base) | `(−21.2, 66.5)`, `(−21.2, 96.5)`, `(8.8, 66.5)`, `(8.8, 96.5)` → **vuông 30.0 × 30.0mm** | **2.8 mm** | Lỗ **tự-ren M3** | ✅ **Interface lắp thân ống** — mặt bích đỉnh ống bắt 4 vít M3 vào đây |
| **4 lỗ ốc M3** (lid) | trùng 4 góc trên | **3.2 mm** | Lỗ **thông M3** (clearance) | ✅ Đối ứng với base |
| **Lỗ camera** (tâm) | `(−6.15, 81.55)` = **trục quang** | **7.5 mm** | Khẩu độ camera THẬT | ✅ GIỮ — lòng ống đồng tâm điểm này |
| **3 lỗ ⌀8mm** vây quanh | `(7.1, 95.0)`, `(−19.6, 68.0)`, `(−15.7, 92.5)` | **8.0 mm** | ⚠️ **DI SẢN thiết kế Matchboxscope cũ** | ❌ **BỎ QUA** — không tái tạo, KHÔNG nhầm là lỗ luồn cáp/chức năng |
| 2 lỗ ⌀4mm | `(16.6, 74.4)`, `(0.0, 58.5)` | 4.0 mm | Cắt connector/mép base (nội bộ base) | ❌ Không liên quan lắp ống |

**Ghi chú then chốt cho SCAD:**
- **Tâm cụm 4 lỗ M3 = `(−6.2, 81.5)` = trục quang** (trùng lỗ camera). **Lệch ~0.8mm** so với tâm hình học footprint `(−5.39, 81.53)`. ⟹ Căn `tube_id` / khay / đèn nền **đồng tâm trục quang `(−6.2, 81.5)`**, KHÔNG theo tâm outline.
- Bước lỗ M3 là **30.0 × 30.0mm** (ΔX = 8.8−(−21.2) = 30.0; ΔY = 96.5−66.5 = 30.0).
- **"4 lỗ nhưng 3 lỗ xung quanh thừa"** = cụm tâm quang: 1 lỗ camera (⌀7.5, giữ) + 3 lỗ ⌀8mm (di sản, bỏ). Đây là điểm dễ nhầm khi đọc STL — đã chốt phân loại tại đây.

### 📄 Tệp: `Assembly_Matchboxscope_injectionmolded_xiao_IM_Matchboxscope_base_xiao_lid_10.stl`
- **Kích thước hộp bao (Bounding Box)**: 50.42 mm (X) x 52.00 mm (Y) x 2.00 mm (Z)
- **Thể tích (Volume)**: 3629.72 mm³
- **Diện tích bề mặt (Surface Area)**: 4110.30 mm²
- **Vật thể kín (Is Closed Manifold)**: Có (Watertight)
- **Các tính năng hình học phát hiện được**:
  * **Mặt cắt vuông góc trục Z**:
    * Đường kính ~ **3.2 mm** (Bán kính 1.6 mm) tại các tâm: `[-21.2, 96.5, -33.7]; [-21.2, 66.5, -33.7]; [8.8, 66.5, -33.7]; [8.8, 96.5, -33.7]; [-21.2, 66.5, -32.8]; [8.8, 96.5, -32.8]; [8.8, 66.5, -32.8]; [-21.2, 96.5, -32.8]`
  * **Độ dày / Khoảng cách phẳng trên trục Y**: 32.2 mm

## 📁 Thư mục: `perestaltic pump`
### 📄 Tệp: `Planktoscope_Mini_Peristalticpump_new_00_Bearing_4x13.5_9.stl`
- **Kích thước hộp bao (Bounding Box)**: 13.00 mm (X) x 13.00 mm (Y) x 5.00 mm (Z)
- **Thể tích (Volume)**: 600.74 mm³
- **Diện tích bề mặt (Surface Area)**: 507.31 mm²
- **Vật thể kín (Is Closed Manifold)**: Có (Watertight)
- **Các tính năng hình học phát hiện được**:
  * **Mặt cắt vuông góc trục Z**:
    * Đường kính ~ **4.0 mm** (Bán kính 2.0 mm) tại các tâm: `[123.6, 26.9, 6.8]; [123.6, 26.9, 7.7]; [123.6, 26.9, 8.7]; [123.6, 26.9, 9.6]; [123.6, 26.9, 10.6]`
    * Đường kính ~ **13.0 mm** (Bán kính 6.5 mm) tại các tâm: `[123.6, 26.9, 6.8]; [123.6, 26.9, 7.7]; [123.6, 26.9, 8.7]; [123.6, 26.9, 9.6]; [123.6, 26.9, 10.6]`

### 📄 Tệp: `Planktoscope_Mini_Peristalticpump_new_Pump_Base_Motor_new_5.stl`
- **Kích thước hộp bao (Bounding Box)**: 51.99 mm (X) x 52.00 mm (Y) x 20.50 mm (Z)
- **Thể tích (Volume)**: 14975.07 mm³
- **Diện tích bề mặt (Surface Area)**: 12213.83 mm²
- **Vật thể kín (Is Closed Manifold)**: Có (Watertight)
- **Các tính năng hình học phát hiện được**:
  * **Mặt cắt vuông góc trục Y**:
    * Đường kính ~ **2.8 mm** (Bán kính 1.4 mm) tại các tâm: `[83.2, -24.6, -5.4]; [53.2, -24.6, -5.4]; [83.2, -17.3, -5.4]; [53.2, -17.3, -5.4]; [83.2, 4.7, -5.4]; [53.2, 4.7, -5.4]; [53.2, 12.1, -5.4]; [83.2, 12.1, -5.4]; [53.2, 15.7, -5.4]; [83.2, 15.7, -5.4]; [83.2, 19.4, -5.4]; [53.2, 19.4, -5.4]`
  * **Mặt cắt vuông góc trục Z**:
    * Đường kính ~ **2.8 mm** (Bán kính 1.4 mm) tại các tâm: `[53.2, -21.3, -22.6]; [53.2, 8.7, -22.6]; [85.7, -6.3, -22.6]; [50.7, -6.3, -22.6]; [83.2, -21.3, -22.6]; [83.2, 8.7, -22.6]`
    * Đường kính ~ **3.2 mm** (Bán kính 1.6 mm) tại các tâm: `[83.2, 8.7, -21.2]; [53.2, 8.7, -21.2]; [83.2, -21.3, -21.2]; [53.2, -21.3, -21.2]; [83.2, 8.7, -19.8]; [53.2, 8.7, -19.8]; [83.2, -21.3, -19.8]; [53.2, -21.3, -19.8]; [53.2, 8.7, -18.3]; [83.2, 8.7, -18.3]; [53.2, -21.3, -18.3]; [83.2, -21.3, -18.3]; [83.2, 8.7, -16.9]; [83.2, -21.3, -16.9]; [53.2, 8.7, -16.9]; [53.2, -21.3, -16.9]; [83.2, 8.7, -15.5]; [53.2, 8.7, -15.5]; [83.2, -21.3, -15.5]; [53.2, -21.3, -15.5]; [83.2, 8.7, -14.1]; [83.2, -21.3, -14.1]; [53.2, 8.7, -14.1]; [53.2, -21.3, -14.1]; [83.2, 8.7, -12.6]; [53.2, -21.3, -12.6]; [53.2, 8.7, -12.6]; [83.2, -21.3, -12.6]; [83.2, 8.7, -11.2]; [53.2, 8.7, -11.2]; [83.2, -21.3, -11.2]; [53.2, -21.3, -11.2]; [83.2, -21.3, -9.8]; [83.2, 8.7, -9.8]; [53.2, -21.3, -9.8]; [53.2, 8.7, -9.8]; [83.2, 8.7, -8.4]; [53.2, -21.3, -8.4]; [53.2, 8.7, -8.4]; [83.2, -21.3, -8.4]; [53.2, -21.3, -7.0]; [83.2, -21.3, -7.0]; [83.2, 8.7, -7.0]; [53.2, 8.7, -7.0]`
    * Đường kính ~ **6.5 mm** (Bán kính 3.2 mm) tại các tâm: `[53.2, 8.7, -2.7]; [83.2, 8.7, -2.7]; [83.2, -21.3, -2.7]; [53.2, -21.3, -2.7]`
    * Đường kính ~ **12.0 mm** (Bán kính 6.0 mm) tại các tâm: `[68.2, -14.3, -22.6]`
    * Đường kính ~ **52.9 mm** (Bán kính 26.4 mm) tại các tâm: `[68.2, -5.5, -22.6]; [68.2, -5.5, -21.2]; [68.2, -5.5, -19.8]; [68.2, -5.5, -18.3]; [68.2, -5.5, -16.9]; [68.2, -5.5, -15.5]; [68.2, -5.5, -14.1]; [68.2, -5.5, -12.6]; [68.2, -5.5, -11.2]; [68.2, -5.5, -9.8]; [68.2, -5.5, -8.4]; [68.2, -5.5, -7.0]`
  * **Độ dày / Khoảng cách phẳng trên trục X**: 2.1 mm, 28.1 mm, 2.1 mm
  * **Độ dày / Khoảng cách phẳng trên trục Z**: 16.0 mm

### 📄 Tệp: `Planktoscope_Mini_Peristalticpump_new_Pump_Base_Motor_tubeholder_new_2.stl`
- **Kích thước hộp bao (Bounding Box)**: 52.00 mm (X) x 53.09 mm (Y) x 11.00 mm (Z)
- **Thể tích (Volume)**: 15201.40 mm³
- **Diện tích bề mặt (Surface Area)**: 7775.37 mm²
- **Vật thể kín (Is Closed Manifold)**: Có (Watertight)
- **Các tính năng hình học phát hiện được**:
  * **Mặt cắt vuông góc trục Y**:
    * Đường kính ~ **2.8 mm** (Bán kính 1.4 mm) tại các tâm: `[53.2, 11.9, -30.4]; [83.2, 11.9, -30.4]; [53.2, 15.7, -30.4]; [83.2, 15.7, -30.4]; [83.2, 19.4, -30.4]; [53.2, 19.4, -30.4]`
    * Đường kính ~ **4.0 mm** (Bán kính 2.0 mm) tại các tâm: `[52.9, -25.6, -30.4]; [83.5, -25.6, -30.4]`
  * **Mặt cắt vuông góc trục Z**:
    * Đường kính ~ **2.8 mm** (Bán kính 1.4 mm) tại các tâm: `[53.2, 8.7, -33.6]; [83.2, 8.7, -33.6]; [53.2, 8.7, -32.1]; [83.2, 8.7, -32.1]; [53.2, 8.7, -30.6]; [83.2, 8.7, -30.6]; [83.2, 8.7, -29.1]; [53.2, 8.7, -29.1]; [83.2, 8.7, -27.7]; [53.2, 8.7, -27.7]; [53.2, 8.7, -26.2]; [83.2, 8.7, -26.2]; [53.2, 8.7, -24.7]; [83.2, 8.7, -24.7]; [83.2, -21.3, -23.2]; [53.2, -21.3, -23.2]; [53.2, 8.7, -23.2]; [83.2, 8.7, -23.2]`
    * Đường kính ~ **3.0 mm** (Bán kính 1.5 mm) tại các tâm: `[50.7, -6.3, -33.6]; [85.7, -6.3, -33.6]; [85.7, -6.3, -32.1]; [50.7, -6.3, -32.1]; [85.7, -6.3, -30.6]; [50.7, -6.3, -30.6]; [50.7, -6.3, -29.1]; [85.7, -6.3, -29.1]; [50.7, -6.3, -27.7]; [85.7, -6.3, -27.7]; [50.7, -6.3, -26.2]; [85.7, -6.3, -26.2]; [50.7, -6.3, -24.7]; [85.7, -6.3, -24.7]; [50.7, -6.3, -23.2]; [85.7, -6.3, -23.2]`
    * Đường kính ~ **12.0 mm** (Bán kính 6.0 mm) tại các tâm: `[68.2, -14.3, -23.2]`
    * Đường kính ~ **32.4 mm** (Bán kính 16.2 mm) tại các tâm: `[68.2, -14.4, -33.6]; [68.2, -14.4, -26.9]; [68.2, -14.4, -25.4]; [68.2, -14.4, -23.9]`
    * Đường kính ~ **33.0 mm** (Bán kính 16.5 mm) tại các tâm: `[68.2, -14.3, -27.7]`
    * Đường kính ~ **33.4 mm** (Bán kính 16.7 mm) tại các tâm: `[68.2, -14.3, -28.4]`
    * Đường kính ~ **53.1 mm** (Bán kính 26.6 mm) tại các tâm: `[68.2, -5.7, -33.6]; [68.2, -5.7, -28.4]; [68.2, -5.7, -26.9]; [68.2, -5.7, -25.4]; [68.2, -5.7, -23.9]`
  * **Độ dày / Khoảng cách phẳng trên trục X**: 32.2 mm

### 📄 Tệp: `Planktoscope_Mini_Peristalticpump_new_Pump_Base_Motor_tubeholder_new__3.stl`
- **Kích thước hộp bao (Bounding Box)**: 52.00 mm (X) x 52.00 mm (Y) x 13.00 mm (Z)
- **Thể tích (Volume)**: 18051.00 mm³
- **Diện tích bề mặt (Surface Area)**: 7201.90 mm²
- **Vật thể kín (Is Closed Manifold)**: Có (Watertight)
- **Các tính năng hình học phát hiện được**:
  * **Mặt cắt vuông góc trục Y**:
    * Đường kính ~ **4.0 mm** (Bán kính 2.0 mm) tại các tâm: `[132.7, 9.0, 9.5]; [102.9, 9.0, 9.5]`
  * **Mặt cắt vuông góc trục Z**:
    * Đường kính ~ **2.8 mm** (Bán kính 1.4 mm) tại các tâm: `[100.3, 27.4, 4.8]; [135.3, 27.4, 4.8]; [100.3, 27.4, 5.7]; [135.3, 27.4, 5.7]; [100.3, 27.4, 6.6]; [135.3, 27.4, 6.6]; [100.3, 27.4, 7.5]; [135.3, 27.4, 7.5]; [135.3, 27.4, 8.3]; [100.3, 27.4, 8.3]; [135.3, 27.4, 9.2]; [100.3, 27.4, 9.2]; [100.3, 27.4, 10.1]; [135.3, 27.4, 10.1]; [135.3, 27.4, 11.0]; [100.3, 27.4, 11.0]; [100.3, 27.4, 11.9]; [135.3, 27.4, 11.9]; [100.3, 27.4, 12.8]; [135.3, 27.4, 12.8]; [135.3, 27.4, 13.7]; [100.3, 27.4, 13.7]; [100.3, 27.4, 14.5]; [135.3, 27.4, 14.5]; [100.3, 27.4, 15.4]; [135.3, 27.4, 15.4]; [135.3, 27.4, 16.3]; [100.3, 27.4, 16.3]; [135.3, 27.4, 17.2]; [100.3, 27.4, 17.2]`
    * Đường kính ~ **12.0 mm** (Bán kính 6.0 mm) tại các tâm: `[117.8, 19.4, 14.5]; [117.8, 19.4, 15.4]; [117.8, 19.4, 16.3]; [117.8, 19.4, 17.2]`
    * Đường kính ~ **52.0 mm** (Bán kính 26.0 mm) tại các tâm: `[117.8, 27.4, 14.5]; [117.8, 27.4, 15.4]; [117.8, 27.4, 16.3]; [117.8, 27.4, 17.2]`
  * **Độ dày / Khoảng cách phẳng trên trục X**: 32.2 mm

### 📄 Tệp: `Planktoscope_Mini_Peristalticpump_new_Pump_Rotatio_new_4.stl`
- **Kích thước hộp bao (Bounding Box)**: 25.00 mm (X) x 25.00 mm (Y) x 9.60 mm (Z)
- **Thể tích (Volume)**: 3015.74 mm³
- **Diện tích bề mặt (Surface Area)**: 2753.66 mm²
- **Vật thể kín (Is Closed Manifold)**: Có (Watertight)
- **Các tính năng hình học phát hiện được**:
  * **Mặt cắt vuông góc trục Z**:
    * Đường kính ~ **3.8 mm** (Bán kính 1.9 mm) tại các tâm: `[76.4, -9.5, -31.7]; [68.3, -23.8, -31.7]; [59.9, -9.6, -31.7]; [76.4, -9.5, -30.4]; [68.3, -23.8, -30.4]; [59.9, -9.6, -30.4]; [76.4, -9.5, -29.1]; [68.3, -23.8, -29.1]; [59.9, -9.6, -29.1]; [68.3, -23.8, -27.8]; [76.4, -9.5, -27.8]; [59.9, -9.6, -27.8]; [76.4, -9.5, -26.5]; [59.9, -9.6, -26.5]; [68.3, -23.8, -26.5]`
    * Đường kính ~ **4.4 mm** (Bán kính 2.2 mm) tại các tâm: `[68.2, -14.3, -33.6]; [68.2, -14.3, -32.3]; [68.2, -14.3, -31.0]; [68.2, -14.3, -29.7]; [68.2, -14.3, -28.5]; [68.2, -14.3, -27.2]; [68.2, -14.3, -25.9]; [68.2, -14.3, -24.6]`
    * Đường kính ~ **25.0 mm** (Bán kính 12.5 mm) tại các tâm: `[68.2, -14.3, -33.6]; [68.2, -14.3, -32.3]; [68.2, -14.3, -25.9]; [68.2, -14.3, -24.6]`
  * **Độ dày / Khoảng cách phẳng trên trục Z**: 2.9 mm, 2.7 mm

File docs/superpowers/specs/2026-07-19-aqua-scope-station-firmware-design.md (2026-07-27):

# Thiết kế: Firmware chính thức `aqua_scope_station` + đường chạy liền mạch board → model → web

Ngày: 2026-07-19
Trạng thái: đã duyệt (brainstorming), chờ lập plan

## 1. Vấn đề

Các mảnh của dự án đều đã chạy được, nhưng **chưa nối thành một hệ**:

- `dataset_collector/firmware/` — bản ESP32-CAM tốt nhất hiện có (backlit defaults,
  prefs flash, `/capture`), nhưng được đóng khung là **công cụ thu dataset**, không phải
  firmware của trạm đo.
- `firmware/Esp32 cam/`, `firmware/aqua_scope_cam/`, `firmware/esp32-cam-webserver/`,
  `firmware/pump_stopflow_test/` — thử nghiệm hoặc tiền đề, không rõ bản nào là bản nạp.
- `ml/infer` — chạy được, nhưng chỉ đọc **thư mục ảnh** trên đĩa.
- `web/backend` — nhận `/api/ingest` và hiển thị dashboard, đã hoạt động.

Hệ quả: để đo một mẫu, phải chạy `collect_dataset.py` tải ảnh về thư mục, rồi mới chạy
`ml.infer` trỏ vào thư mục đó. Hai bước rời, và không có gì trong sổ audit cho biết ảnh
đến từ board nào ở thiết lập camera nào.

## 2. Quyết định kiến trúc

**PC là nhạc trưởng.** Firmware là nguồn ảnh + (sau này) cơ cấu chấp hành; PC điều phối
chu trình đo, chạy suy luận, ghi sổ audit.

Lý do chọn hướng này thay vì để ESP32 tự POST ảnh lên backend: backend hiện nhận ảnh
**kèm danh sách particles** đã suy luận. Nếu board POST ảnh trần, mọi Sample sẽ có
`particle_count = 0` và phải viết lại cả backend lẫn `ml/infer` thành kiến trúc
pull/worker. Đổi lại, hệ cần có PC bật thì mới đo được — chấp nhận được vì đây là
demo/lab rig, và chu trình vốn là **lấy mẫu theo lô/định kỳ**, không phải giám sát 24/7.

Ràng buộc phần cứng hiện tại thu hẹp phạm vi firmware đáng kể:

- **Đèn nền cắm điện trực tiếp, luôn sáng** → firmware không điều khiển đèn.
- **Chưa cần điều khiển bơm** → không gộp state machine của `pump_stopflow_test`.

Còn lại đúng: camera + WiFi + phục vụ ảnh + báo cáo trạng thái.

## 3. Phần A — Firmware `firmware/aqua_scope_station/`

Bản chính thức duy nhất của dự án. Kế thừa nguyên phần đã chạy tốt của
`dataset_collector/firmware`: mặc định backlit (tắt AEC / AEC-DSP / AGC, gain 0,
exposure thấp), mặc định UXGA, `aqua_prefs` lưu/nạp cấu hình vào NVS, web UI canh sáng,
`/capture`, `/stream`, `/control?var=save|reset`.

### A0. Tắt đèn flash khi chụp (phát hiện lúc lập plan)

`capture_handler` của bản Espressif bật **đèn flash trắng GPIO4 trong 150ms trước mỗi
lần chụp** (`LED_GPIO_NUM 4` được định nghĩa cho AI-Thinker, `camera_pins.h:180`).

Với rig backlit silhouette, đó là ánh sáng chiếu **từ trên xuống** mặt nước: làm nhạt
tương phản bóng hạt và tạo phản xạ trên mặt nước — đúng thứ toàn bộ thiết kế quang học
đang cố tránh. Bản chính thức phải bỏ hẳn, đồng thời bỏ luôn 150ms trễ mỗi khung.

### A1. `GET /device` → JSON

Endpoint mới. **Tên là `/device`, không phải `/status`**: `/status` đã bị chiếm bởi
handler trả JSON cấu hình camera mà web UI dùng để nạp slider (`app_httpd.cpp:431`) —
đổi nó sẽ làm hỏng trang canh sáng.

Trả về:

```json
{
  "device_id": "aqua-cam-a1b2c3",
  "firmware": "aqua_scope_station/1.0.0",
  "uptime_s": 4512,
  "wifi": { "ssid": "...", "rssi": -58, "ip": "192.168.1.50" },
  "psram": true,
  "sensor": "OV2640",
  "camera": {
    "framesize": "UXGA", "width": 1600, "height": 1200, "quality": 10,
    "aec": 0, "aec2": 0, "agc": 0, "gain": 0, "exposure": 100
  },
  "captures": 137,
  "prefs_saved": true
}
```

Vì sao cần: yêu cầu truy xuất nguồn gốc của dự án đòi hỏi biết một mẫu được chụp
**bởi board nào, ở thiết lập camera nào**. `prefs_saved: false` là cảnh báo trực tiếp
cho lỗi hay gặp nhất trong README hiện tại ("nền trắng xóa, không thấy hạt" — do board
boot lại về auto vì chưa `var=save`). PC gọi endpoint này một lần trước khi chạy và
nhét nguyên khối vào metadata của mẫu.

### A2. `device_id` ổn định

Sinh từ MAC: `aqua-cam-` + 3 byte cuối dạng hex thường (ví dụ `aqua-cam-a1b2c3`).
Ghi đè được bằng `GET /control?var=device_id&val=<chuỗi>`, lưu cùng chỗ với prefs
camera trong NVS.

Vì sao: hiện `ingest.device_id` trong `ml/config.toml` là hằng `"pc-infer"` — mọi mẫu
đều mang chung một tên. Với sổ audit thì cột đó phải chỉ ra **thiết bị đo thật**.

Ràng buộc: `device_id` giữ trong tập ký tự `^[A-Za-z0-9._-]{1,64}$`, cùng tập với
`SAMPLE_CODE_PATTERN` của web (`web/backend/app/models.py`).

**Đính chính (phát hiện khi review Task 2):** ban đầu bản thiết kế này ghi rằng web dùng
`device_id` nguyên văn làm tên file ảnh. **Sai.** Tên file dựng từ `sample_code`
(`routers/ingest.py`), còn `device_id` chỉ là một cột string và **không có validator nào**
phía server. Ràng buộc trên vì thế là **phòng thủ chủ động ở nguồn**, không phải vá một lỗ
hổng đang mở — giữ nó an toàn để sau này dùng được ở mọi chỗ mà không phải rà lại.

### A3. Độ bền khi chạy dài

| Vấn đề ở bản hiện tại | Xử lý |
|---|---|
| Rớt WiFi giữa chừng là đứng luôn | Nối lại qua WiFi event handler, **không dùng vòng `while` chặn**. Vẫn phục vụ HTTP ngay khi có lại IP. |
| `esp_camera_fb_get()` trả `NULL` → phản hồi cụt, client không biết vì sao | Trả **HTTP 503** kèm body lý do rõ ràng. Không bao giờ trả 200 với thân rỗng. |
| Board treo phải rút điện | Bật task watchdog cho vòng lặp chính. |

### A4. Cố tình KHÔNG có trong phạm vi này

- Điều khiển đèn nền (đèn cắm thẳng).
- Điều khiển bơm / state machine Stop-Flow (`pump_stopflow_test` vẫn đứng riêng).
- Suy luận on-device.

Không viết sẵn code cho những thứ này. Chỗ để dành duy nhất được chấp nhận: `/device`
có cấu trúc mở rộng được, và README ghi rõ bơm sẽ vào ở đâu khi tới lúc.

## 4. Phần B — `ml/infer` đọc thẳng từ board

### B1. `Esp32CaptureSource`

Thêm vào `ml/infer/source.py`, **cùng interface `.frames()`** với `FolderSource`
(docstring của file đã dự trù sẵn lớp này). Nhờ vậy `cli.py`, `mapper.py`,
`ingest_client.py` không phải sửa gì ngoài chỗ chọn source.

Hành vi:

- `GET http://<host>/device` một lần lúc khởi tạo → giữ lại để nhét vào metadata.
  Nếu không gọi được → báo lỗi rõ ràng và dừng, **không** âm thầm chạy tiếp.
- Lặp `--count` lần: `GET /capture`, nghỉ `--interval` giây giữa hai lần.
- Mỗi lần chụp lỗi (timeout / 503 / body không phải JPEG) → thử lại `retries` lần,
  hết thì bỏ qua khung đó và ghi log, **không** làm hỏng cả lượt chạy.
- `captured_at` lấy theo giờ PC lúc nhận được ảnh (timezone-aware UTC).
- `sample_code` sinh dạng `S{yyyyMMdd}-{HHmmss}-{mmm}` từ thời điểm chụp — cùng dạng với
  mã do server sinh, và khớp sẵn `^[A-Za-z0-9._-]{1,64}$` nên không cần làm sạch thêm.
  Phần mili-giây là thứ giữ cho hai khung chụp liền nhau không trùng mã.

### B2. CLI

```bash
python -m ml.infer --from-board 192.168.1.50 --count 5 --interval 2
```

- `--from-board <host>` loại trừ lẫn nhau với đối số `input` (thư mục ảnh). Đưa cả hai
  → lỗi rõ ràng, không đoán.
- Bỏ `--from-board` mà `[station].host` đã khai trong config → dùng giá trị đó.
- `--dry-run`, `--check-config` hoạt động y hệt. `--dry-run` vẫn chụp thật nhưng **không
  POST** — DB là sổ audit, mỗi lần chạy thật là một bản ghi vĩnh viễn.
- `--device-id` không đưa → dùng `device_id` **board tự báo** (không phải hằng trong
  config). Đưa tay → giá trị tay thắng, theo đúng thứ tự ưu tiên hiện có của config.

### B3. Config

Thêm mục vào `ml/config.toml`:

```toml
[station]
host = ""          # IP hoặc hostname của board, lấy từ Serial Monitor
timeout_s = 20     # timeout mỗi request (UXGA qua WiFi có thể lâu)
retries = 3        # số lần thử lại mỗi khung ảnh
interval_s = 2.0   # nghỉ giữa hai lần chụp
```

`config.missing_for("station")` kiểm tra mục này, và `--check-config` phải báo cáo nó
**cùng lúc** với backend suy luận — hai thứ trực giao: đọc từ board vẫn chạy được cả
`local` lẫn `roboflow`.

## 5. Ranh giới với `dataset_collector`

`collect_dataset.py` chạy nguyên vẹn với firmware mới (cùng `/capture`). **Không gộp.**

| | `collect_dataset.py` | `ml.infer --from-board` |
|---|---|---|
| Mục đích | thu ảnh thô để **train** | đo mẫu thật để **ghi sổ audit** |
| Đầu ra | file JPEG trong `data/dataset/` | dòng Sample + Particle trong DB |
| Chạy suy luận | không | có |

Gộp lại sẽ buộc công cụ thu dataset phải mang theo cả detector và kết nối DB — hai thứ
nó không cần.

## 6. Các firmware cũ

Giữ nguyên, không xóa. Thêm một dòng ở đầu README mỗi thư mục:

> Tham khảo/thử nghiệm — bản chính thức để nạp là `firmware/aqua_scope_station/`.

`dataset_collector/firmware/` là trường hợp riêng: nó bị **thay thế** bởi bản mới
(bản mới là hậu duệ trực tiếp). README của `dataset_collector` phải nói rõ dùng
`firmware/aqua_scope_station/` và giữ `collect_dataset.py` như cũ.

## 7. Kiểm chứng

**Phần Python** — test theo đúng kiểu `dataset_collector/tests` đang làm: dựng HTTP
server thật trên localhost giả lập board, để bắt các ca hỏng ngoài đời mà mock
`requests` sẽ bỏ lọt:

- `/device` không gọi được → lỗi rõ ràng, dừng
- `/device` trả JSON thiếu khóa → không sập, báo thiếu
- `/capture` timeout → thử lại đủ số lần rồi bỏ qua khung
- `/capture` trả HTML kèm HTTP 200 → nhận ra không phải JPEG
- `/capture` trả 503 → bỏ qua khung, chạy tiếp
- body JPEG cụt giữa chừng → không đẩy rác vào detector
- brownout giữa burst (server chết giữa lượt) → các khung đã lấy vẫn được xử lý
- `--dry-run` → không có request POST nào chạm tới ingest

**Phần firmware** — không test tự động được. Nghiệm thu bằng checklist chạy trên board
thật, ghi vào README, và **không tuyên bố "chạy được" trước khi chạy đủ checklist**:

1. Nạp, mở Serial 115200 → thấy IP.
2. `GET /device` → JSON hợp lệ, `device_id` khớp MAC, `psram: true`.
3. Web UI canh sáng → nền xám đều, hạt là bóng đen.
4. `var=save` → rút điện → cắm lại → `/device` báo `prefs_saved: true` và đúng thông số.
5. Tắt router 30 giây rồi bật lại → board tự nối lại, `/device` phản hồi, không cần reset.
6. `python -m ml.infer --from-board <ip> --count 3 --dry-run` → 3 khung, không ghi DB.
7. Bỏ `--dry-run` → 3 mẫu hiện trên dashboard, cột device_id đúng tên board.

## 8. Ngoài phạm vi

- Điều khiển bơm và hợp nhất state machine Stop-Flow.
- Điều khiển đèn nền qua GPIO.
- Suy luận on-device trên ESP32-CAM.
- Hiệu chuẩn `px_per_mm` thật trên rig (đến khi có, `size_mm` vẫn là placeholder và
  CLI vẫn phải cảnh báo mỗi lần chạy).
- Dọn/xóa các thư mục firmware cũ.

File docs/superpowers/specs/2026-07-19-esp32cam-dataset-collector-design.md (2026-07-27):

# Thiết kế: Bộ thu thập dataset ESP32-CAM

**Ngày:** 2026-07-19
**Trạng thái:** đã triển khai (`dataset_collector/`)

## 1. Mục tiêu

Có một cách lặp lại được để **chụp ảnh backlit trên ESP32-CAM và kéo về laptop**
làm dataset huấn luyện detector. Kèm chức năng web-cam để canh sáng bằng mắt.

Phần cứng: **ESP32-CAM AI-Thinker (OV2640)** — biến thể `cam_variant=1` trong
`openscad/`, lắp qua cùng interface 4×M3 30×30 với bản XIAO.

## 2. Kiến trúc

Hai thành phần, ranh giới cứng:

| Thành phần | Trách nhiệm | Không làm |
|---|---|---|
| `dataset_collector/firmware/` | phục vụ ảnh qua HTTP (`/`, `/stream`, `/capture`, `/control`) | không đặt tên file, không lưu trữ, không biết "dataset" là gì |
| `dataset_collector/collect_dataset.py` | burst, đặt tên, retry, ghi đĩa | không chỉnh camera |

**Hệ quả có chủ đích:** thay đổi cách thu dataset (số lượng, nhịp, thư mục,
lọc ảnh) không cần nạp lại firmware. Đây là lý do chính chọn hướng
**laptop-kéo** thay vì ESP32-đẩy.

Luồng: `collect_dataset.py --count N` → lặp N lần `GET /capture` → kiểm tra
JPEG hợp lệ → ghi `web/backend/data/dataset/YYYYmmdd-HHMMSS-mmm.jpg`.

## 3. Quyết định & đánh đổi

### 3.1 Laptop kéo, không phải ESP32 đẩy
Firmware giữ được sự đơn giản (là bản stock + 3 sửa nhỏ). Đổi lại: phải biết IP
của board, và không tự chụp khi không có laptop. Chấp nhận được — thu dataset
vốn là hoạt động có người ngồi cạnh.

### 3.2 Thư mục mới `data/dataset/`, KHÔNG dùng `data/images/`
Yêu cầu ban đầu là ghi vào `data/images/`. Đã đổi vì thư mục đó có bất biến:
mỗi file khớp đúng một dòng `Sample` trong DB, tên cứng `{sample_code}.jpg`
(`web/backend/app/routers/ingest.py`). Ảnh thô ở đó sẽ là **file mồ côi** —
web không hiển thị, lại lẫn với `MOCK-*.jpg` của `mock_sender.py`.

`data/dataset/` vẫn nằm trong khu `data` của web (đúng tinh thần yêu cầu) nhưng
không phá mô hình dữ liệu. Có test khóa quyết định này lại
(`test_main_does_not_default_to_the_web_sample_images_dir`).

**Rủi ro đã biết:** `web/backend/data/` bị git-ignore → dataset không được version.
Chấp nhận (không nên commit hàng trăm JPEG), nhưng đã ghi cảnh báo trong README.

### 3.3 Thư mục riêng ở gốc repo, không nằm trong `firmware/`
`firmware/` đang chứa 3 bản web-cam thông thường. Bộ này là **công cụ hoàn chỉnh
gồm cả hai nửa** (board + laptop), để lẫn vào đó sẽ mất ranh giới đó.

### 3.4 Firmware = bản stock Espressif + 3 sửa
Bản `CameraWebServer` của Espressif đã có sẵn mọi endpoint cần thiết. Viết lại
từ đầu là phí. Ba điểm sửa:

1. **Ép mặc định backlit** (`aqua_prefs.cpp`): tắt AEC / AEC-DSP / AGC, gain 0,
   exposure 100, contrast +1. Bản gốc để auto → nền cháy trắng, nuốt mất hạt.
   Thứ tự quan trọng: phải tắt vòng tự động **trước** khi đặt giá trị thủ công.
2. **Mặc định UXGA** thay vì QVGA. OV2640 tối đa UXGA 1600×1200 — kém OV3660
   (QXGA) trên bản XIAO; đây là giới hạn phần cứng cần biết khi đo hạt <2mm.
3. **Lưu cấu hình vào flash** (NVS) + `?var=save` / `?var=reset`. Không có nó thì
   mỗi lần mất điện phải canh sáng lại từ đầu.

Sửa thêm ngoài kế hoạch: **WiFi không treo vô hạn** — bản gốc lặp `while` mãi mãi
khi sai mật khẩu; bản này hết 20s là báo lỗi rõ ràng.

### 3.5 Không gắn nhãn, không manifest
Ảnh lưu phẳng theo timestamp. Gắn nhãn sau bằng công cụ riêng (Roboflow).

## 4. Kiểm thử

`dataset_collector/tests/` — 20 test, dựng **HTTP server thật trên localhost**
làm ESP32-CAM giả thay vì mock `requests`. Lý do: các kiểu hỏng cần bắt đều nằm
ở tầng giao thức/dữ liệu, mock sẽ bỏ lọt:

- body cụt (board sập giữa lúc truyền) — có SOI, thiếu EOI
- **trả HTML kèm HTTP 200** — hỏng âm thầm, nguy hiểm nhất
- timeout, host không tồn tại, HTTP 500
- retry rồi thành công; 1 ảnh hỏng không được làm dừng cả phiên
- trùng tên do 2 ảnh trong cùng mili giây → không bao giờ ghi đè
- JPEG có đệm `\x00` sau EOI vẫn phải được **chấp nhận** (loại nhầm ảnh thật còn
  tệ hơn lọt ảnh hỏng)

**Bug thật tìm được lúc chạy:** console Windows mặc định cp1252 không mã hóa được
tiếng Việt → script crash ngay dòng in đầu tiên. `capsys` của pytest không bắt
được vì không đi qua encoding của console. Đã fix (`_force_utf8_output()`) và
khóa lại bằng test chạy tiến trình con với `PYTHONIOENCODING=cp1252`.

Firmware: compile sạch bằng `arduino-cli` với
`esp32:esp32:esp32cam:PartitionScheme=huge_app` (34% flash, 21% RAM).
**Chưa test trên phần cứng thật** — cần board để xác nhận.

## 5. Việc còn lại

- Nạp lên board thật, xác nhận `/capture` và `save` vào flash hoạt động.
- Đo thực nghiệm `--interval` tối thiểu trước khi board brownout.
- Chưa quyết định: có mount `/dataset` để xem ảnh trên web hay không (1 dòng
  trong `main.py`, làm khi thực sự cần).

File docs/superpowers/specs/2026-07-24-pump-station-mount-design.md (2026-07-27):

# Thiết kế: Trạm bơm gọn (đế liền + hộp L298N + kẹp bơm RS365)

**Ngày:** 2026-07-24
**Trạng thái:** Đã duyệt bởi user, chờ viết plan triển khai.

## Bối cảnh

Hiện tại "trạm bơm" trong `openscad/aqua_scope_assembly_001.scad` chỉ có
`pump_rs365()` — một placeholder bounding-box (90×40×35mm, KHÔNG in) đặt tách
rời trên bàn, nối bằng `silicone_tube()`. Không có mount/enclosure thật nào để
giữ bơm cố định hay gá mạch điều khiển; dây điện và dây tín hiệu hiện chưa có
chỗ đi tuyến gọn gàng.

Người dùng đang dùng **module L298N** để điều khiển bơm (khác với tài liệu
hiện có trong repo: `plan.md`/`HUONG_DAN_LAP_RAP.md` ghi "module relay", còn
`firmware/pump_pwm_test/pump_pwm_test.ino` ghi "MOSFET IRLZ44N trực tiếp").
Thiết kế này **chỉ giải quyết phần cơ khí** (mount + đi dây gọn cho in 3D),
không sửa lại lựa chọn driver hay firmware — đó là việc khác, ngoài phạm vi.

## Mục tiêu

Một cụm in 3D duy nhất, gọn, giữ cố định:
1. Board L298N (đã che hộp, có strain-relief dây).
2. Thân bơm màng RS365 (kẹp ôm thân trụ, đầu bơm + ngạnh ống lộ ra ngoài).

Sao cho: bê đi 1 lần, không dây rời rạc lòng thòng giữa 2 vật thể, và hình
dáng in ra nhìn có chủ đích (không phải lắp ráp tạm bằng băng keo/zip-tie
trần).

## Kiến trúc

Một tấm đế (baseplate) in liền mang 2 cụm chức năng ở 2 đầu, nối bằng 1 rãnh
dây ngắn ở giữa:

```
[Yên kẹp bơm ×2]---(rãnh dây ~5cm, gờ giữ dây)---[Hộp L298N + nắp rời]
   ôm thân trụ RS365                          khe dây IN 12V | ra bơm | logic→ESP32
```

### 1. Đế (baseplate)
- Tấm phẳng dày 3mm, kích thước ước lượng ~155mm (dài) × ~50mm (rộng) — đủ
  chứa bbox bơm 90×40 + hộp L298N ~49×49 + rãnh dây giữa.
- 4 chân đế cao 2mm ở góc, in phẳng, không cần support.
- Đế + thành hộp L298N + 2 trụ yên kẹp bơm là **CÙNG MỘT FILE IN** (chỉ nắp
  hộp L298N là chi tiết rời thứ 2).

### 2. Hộp L298N
- Hộp hở nắp, thành dày 2mm.
- Khoang trong ước lượng ~48×48×32mm — rộng hơn kích thước "board L298N phổ
  biến" (~43×43×27mm, đây là số ĐIỂN HÌNH, CHƯA ĐO board thật của user) khoảng
  2.5mm mỗi bên, có chủ đích rộng rãi để dung sai.
- Board tựa trên 4 gờ đỡ góc cao 2mm (không cần khớp đúng lỗ vít của board
  thật — thiết kế "khay hở dung sai" thay vì "khớp lỗ chính xác").
- Nắp rời, bắt 2 vít M3 tự-ren ở 2 góc chéo, tháo được để chỉnh jumper 5V hay
  kiểm tra board.
- 3 khe dây, theo bố trí chân chuẩn của board L298N phổ biến (input 1 cạnh,
  output động cơ 1 cạnh, logic 1 cạnh):
  - Cạnh xa bơm (hướng ra ngoài trạm): khe dây 12V vào từ adapter.
  - Cạnh gần bơm: khe dây ra động cơ, chạy trong rãnh đế tới yên kẹp.
  - Cạnh hướng về khối quang chính: khe bó dây logic (IN1/IN2/EN + GND) lên
    ESP32.
  - Mỗi khe có rãnh bán nguyệt nhỏ ở thành hộp — dây bị ép giữa rãnh và
    nắp/thành đối diện = strain-relief đơn giản, không cần giắc DC rời (theo
    lựa chọn user: xuyên lỗ dây trần + khoét rãnh kẹp).
- Khe hở thoát khí nhỏ đối diện phía tản nhiệt của board.

### 3. Yên kẹp bơm (2 yên)
- 2 trụ đứng từ đế, mỗi trụ có lòng máng ôm ~210° quanh thân trụ RS365.
- Bán kính máng = `pump_motor_od/2 + khe hở`; `pump_motor_od` mặc định lấy
  theo ước tính hiện có trong `accessories_001.scad` (`pump_bbox[2] * 0.9` =
  31.5mm) — **CHƯA ĐO bơm thật, cần xác nhận khi có hàng**.
- Mỗi yên có thêm 1 rãnh vòng nhỏ trên đỉnh để luồn dây rút nhựa (zip-tie)
  xiết chặt thêm, phòng khi đường kính bơm thật lệch so với ước tính — không
  cần in lại đế, chỉ cần xiết zip-tie chặt hơn/lỏng hơn.
- Đầu bơm (khối màng bơm) + 2 ngạnh ống KHÔNG bị che, lộ hẳn ra ngoài để dễ
  tháo lắp ống silicone.

## File / constants cần thêm

- Mới: `openscad/components/pump_station_001.scad` — module `pump_station()`
  chứa đế + hộp L298N (không nắp) + 2 yên kẹp bơm.
  - Giữ nguyên `pump_rs365()` trong `accessories_001.scad` (mô hình hiển thị
    bơm mua sẵn, KHÔNG in) — không đổi.
- Mới: `openscad/print/print_pump_station.scad` (xuất phần đế+hộp+yên) và
  `openscad/print/print_pump_station_lid.scad` (xuất nắp hộp L298N riêng).
- Sửa `openscad/constants.scad`, thêm (đặt cạnh block `pump_bbox`/`pump_barb_od`
  hiện có ở dòng ~163-164):
  - `l298n_l = 43; l298n_w = 43; l298n_h = 27;` — kèm comment "kích thước ĐIỂN
    HÌNH, CHƯA ĐO board thật — sửa lại khi có hàng".
  - `l298n_box_wall = 2;`
  - `l298n_box_clearance = 2.5;` — khe hở mỗi bên quanh board trong hộp.
  - `pump_motor_od = 31.5;` — kèm comment "ước tính từ pump_bbox[2]*0.9, CHƯA
    ĐO bơm thật".
  - `pump_clamp_clearance = 1.0;`
  - `clamp_wrap_deg = 210;`
  - `pump_station_baseplate_t = 3;`
  - `pump_station_foot_h = 2;`
- Sửa `openscad/aqua_scope_assembly_001.scad`: trong khối
  `if (show_pump) { ... }` (dòng ~92-105), thêm `use <components/pump_station_001.scad>`
  và đặt `pump_station()` tại cùng vị trí hiện có của `pump_rs365()`
  (translate `[120 + 1.5*e, 0, z_housing_bot]`), bên dưới bơm — bơm ngồi lên
  yên kẹp thay vì lơ lửng riêng.

## Không làm trong thiết kế này

- Không đổi driver bơm (relay/MOSFET/L298N) hay sửa firmware — chỉ mount cơ
  khí cho L298N mà user đang có.
- Không thiết kế giắc DC barrel jack (user đã chọn xuyên dây trần + rãnh kẹp).
- Không làm kín nước hoàn toàn hộp L298N (chỉ che bụi/dây gọn, không phải hộp
  chống nước IP-rated).

## Giả định cần xác nhận sau (không chặn triển khai, gắn cờ trong code)

1. Kích thước board L298N thật (43×43×27mm chỉ là điển hình).
2. Đường kính thân trụ động cơ RS365 thật (31.5mm chỉ là ước tính).
3. Board L298N thật có đúng bố trí 3 cạnh (input/output/logic) như module phổ
   biến hay không.

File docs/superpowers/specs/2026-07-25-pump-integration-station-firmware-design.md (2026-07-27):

# Gộp điều khiển bơm L298N vào firmware trạm ESP32-CAM — Thiết kế

**Ngày:** 2026-07-25
**Trạng thái:** đã chốt thiết kế; code đã được viết trước bởi một agent khác → tài liệu này đồng thời là **hợp đồng để rà soát lại code đó**.

## 1. Vấn đề

Trước thay đổi này, hai chức năng nằm ở hai firmware trên hai board khác nhau:

| Chức năng | Firmware | Board |
|---|---|---|
| Phục vụ ảnh backlit (`/capture`) cho pipeline Roboflow trên PC | `firmware/aqua_scope_station/` | ESP32-CAM AI-Thinker |
| Chu trình bơm Stop-Flow qua L298N | `firmware/pump_l298n_xiao/` | XIAO ESP32-S3 Sense |

Trạm thật chỉ có **một** MCU (ESP32-CAM). Hai firmware trên hai board là trạng thái tạm của giai đoạn thử nghiệm, không phải thiết kế cuối. Mục tiêu: gộp state machine bơm vào firmware trạm, chạy trên đúng board ESP32-CAM.

## 2. Phạm vi

**Trong phạm vi:** module bơm mới trong firmware trạm; điều khiển qua HTTP + Serial; lưu cấu hình vào flash; báo trạng thái bơm trong `/device`.

**Ngoài phạm vi (cố ý):**
- Firmware **không** tự chụp ảnh theo pha bơm. `/capture` giữ nguyên hành vi hiện tại — PC chủ động pull.
- Không suy luận on-device. Roboflow/YOLO vẫn chạy trên PC (`ml/infer`).
- Không điều khiển đèn nền (đèn cắm thẳng, luôn sáng).
- Không viết script PC tự động bám pha SETTLING — chỉ *lộ* thông tin pha để sau này làm được.

## 3. Kiến trúc

Module mới `aqua_pump.h` / `aqua_pump.cpp`, theo đúng pattern module hoá đã có trong thư mục (`aqua_device.*`, `aqua_prefs.*`) — không nhét thẳng vào `.ino`.

**Ranh giới:** `aqua_pump` chỉ biết điều khiển bơm. Không biết camera, WiFi hay HTTP. Tích hợp HTTP nằm ở `app_httpd.cpp`, Serial ở `.ino`, lưu flash ở `aqua_prefs.cpp`.

State machine port từ `pump_l298n_xiao.ino` (đã kiểm chứng thực nghiệm về ramp chống búa nước):

```
FILLING (bơm chạy fillDuty) → SETTLING (bơm tắt, chụp ảnh)
   → FLUSHING (bơm chạy flushDuty) → COOLDOWN (bơm tắt) → lặp
```

Đồng hồ pha bắt đầu **sau** khi ramp xong, để trọn `fillMs`/`flushMs` thực sự ở mức cruise.

## 4. Phần cứng

| Hạng mục | Giá trị |
|---|---|
| Chân PWM → ENA của L298N | **GPIO13** |
| PWM | 20 kHz, 10-bit (duty 0..1023) |
| IN1 / IN2 | cố định 3.3V / GND — một chiều, không đảo |
| Nguồn L298N + bơm | adapter **12V/2A riêng**, GND chung với ESP32-CAM |

GPIO13 trên AI-Thinker không trùng chân camera (camera dùng 32, 0, 26, 27, 35, 34, 39, 36, 21, 19, 18, 5, 25, 23, 22; LED flash 4). GPIO13 chỉ trùng HS2_DATA3 của khe SD — firmware này không dùng khe SD.

### 4.1 Ràng buộc LEDC (quan trọng)

Camera driver `esp32-camera` tạo XCLK 20 MHz bằng LEDC, cấu hình **trực tiếp qua ESP-IDF** (`ledc_timer_config`/`ledc_channel_config`), nên **không** đăng ký vào Peripheral Manager của Arduino. Hệ quả: `ledcAttach()` của Arduino tin rằng mọi kênh đều rảnh và luôn cấp phát kênh 0.

Trên ESP32 classic điều này *tình cờ* không xung đột, vì Arduino kênh 0 thuộc nhóm **HIGH-speed** còn camera dùng nhóm **LOW-speed** — hai khối timer tách rời về phần cứng. Nhưng đây là **sự trùng hợp không có gì bảo đảm**, không phải thiết kế.

**Yêu cầu:** không được phụ thuộc vào sự trùng hợp đó một cách ngầm định. Kết quả `ledcAttach`/`ledcAttachChannel` **phải được kiểm tra** và báo lỗi rõ ràng nếu thất bại — nếu không, `ledcWrite` sẽ im lặng không làm gì và bơm không bao giờ chạy mà không có bất kỳ thông báo nào.

## 5. An toàn

| Yêu cầu | Lý do |
|---|---|
| GPIO13 bị ép LOW **ở dòng đầu tiên của `setup()`** | ENA thả nổi có thể được L298N đọc là HIGH → bơm chạy hết tốc suốt thời gian còn lại của `setup()` (camera init + WiFi timeout tới 20s). Ép LOW muộn là để hở đúng cửa sổ nguy hiểm đó. |
| `autoRunning` mặc định **TẮT** | Giai đoạn đang lắp/kiểm tra phần cứng mới: cắm điện không được tự xịt nước. Đổi sang tự chạy sau khi nghiệm thu trên board thật. |
| Ramp xuống trước khi tắt bơm | Cắt đột ngột gây búa nước. |

## 6. Giao diện điều khiển

### 6.1 HTTP — mở rộng `/control?var=…&val=…` sẵn có

| `var` | Miền giá trị | Ý nghĩa |
|---|---|---|
| `pump_auto` | 0 / 1 | tắt/bật chu trình auto |
| `pump_fill_ms` | > 0 | thời gian FILLING |
| `pump_settle_ms` | > 0 | thời gian SETTLING |
| `pump_flush_ms` | > 0 | thời gian FLUSHING |
| `pump_cooldown_ms` | > 0 | thời gian COOLDOWN |
| `pump_fill_duty` | 0..100 | duty cruise pha FILL |
| `pump_flush_duty` | 0..100 | duty pha FLUSH |
| `pump_ramp_up_ms` | ≥ 0 | thời gian vuốt lên |
| `pump_ramp_down_ms` | ≥ 0 | thời gian vuốt xuống |

**Giá trị ngoài miền phải bị từ chối rõ ràng (HTTP 500, giống nhánh `framesize`), không được im lặng bỏ qua rồi trả 200.** Trả 200 cho một lệnh không có hiệu lực chính là kiểu hỏng khó truy nhất — người dùng tin là đã đặt được.

### 6.2 Serial (115200)

Bộ lệnh 1 ký tự giữ nguyên từ `pump_l298n_xiao.ino`: `p ? 0 1 a f s x c u w d X r`.

Firmware trạm hiện **không** có bộ lệnh Serial camera nào, nên không có xung đột ký tự.

### 6.3 `/device` JSON

Thêm object `pump`: `auto`, `phase`, `duty`, `cycle_count`, `fill_ms`, `settle_ms`, `flush_ms`, `cooldown_ms`, `ramp_up_ms`, `ramp_down_ms`, `fill_duty`, `flush_duty`.

Trường `phase` để script PC sau này tự biết lúc nào là SETTLING mà gọi `/capture` đúng lúc nước đứng yên. Bản thân firmware không dùng trường này.

## 7. Lưu cấu hình

Mở rộng `aqua_prefs.*`: một nút `?var=save` lưu **cả** cấu hình camera lẫn cấu hình bơm; `?var=reset` xoá cả hai và đưa timing bơm về mặc định. Dùng NVS namespace riêng (`aquapump`) để không va khoá với namespace camera (`aquacam`).

## 8. Đồng thời (concurrency)

Đây là điểm rủi ro nhất của thiết kế và phải xử lý tường minh.

`aquaPumpTick()` chạy trong task `loop()`. Nhưng handler HTTP chạy trong **task httpd riêng**. Nghĩa là `/control?var=pump_auto` có thể gọi vào state machine **đồng thời** với `aquaPumpTick()`.

Nếu cả hai cùng vào `enterPhase()` → `rampDuty()`, hai task sẽ cùng ghi `ledcWrite`, cùng sửa `g_curDuty`/`g_phase`/`g_phaseStart` → duty cuối cùng sai, hoặc đồng hồ pha hỏng. Ngoài ra `rampDuty()` blocking ~350ms sẽ chặn task httpd.

**Yêu cầu:** đường HTTP **không được** tự chạy state machine hay ramp. Nó chỉ được đặt cờ/ghi tham số; mọi thay đổi pha và mọi lần ramp phải xảy ra trong `aquaPumpTick()` ở task `loop()`. Một điểm ghi duy nhất, không cần mutex.

Ghi tham số `PumpTiming` (uint32/uint8) từ task httpd là ghi nguyên tử trên ESP32 — chấp nhận được, không cần khoá.

## 9. Ảnh hưởng tới `loop()`

`loop()` cũ nghỉ 10s mỗi vòng (chia 10 lát 1s). State machine bơm cần độ phân giải cao hơn nhiều, nên `loop()` chuyển sang nhịp ngắn (~50ms) và in trạng thái WiFi theo mốc thời gian (`millis()`) thay vì theo số vòng lặp. Watchdog 30s/5s không bị chạm.

## 10. Tiêu chí nghiệm thu

Đây là checklist để rà soát code hiện có:

- [ ] A1. GPIO13 ép LOW ngay dòng đầu `setup()`, trước camera init và WiFi.
- [ ] A2. Kết quả gắn LEDC được kiểm tra; thất bại thì báo lỗi rõ ràng ra Serial.
- [ ] A3. Kênh LEDC không phụ thuộc ngầm vào sự trùng hợp HS/LS; lý do chọn được ghi đúng trong comment.
- [ ] A4. `autoRunning` mặc định false.
- [ ] A5. Đường HTTP không gọi ramp/đổi pha trực tiếp — chỉ đặt cờ, `aquaPumpTick()` thực thi.
- [ ] A6. Giá trị `/control` ngoài miền → HTTP 500, không phải 200.
- [ ] A7. `?var=save` lưu cả camera + bơm; `?var=reset` xoá cả hai.
- [ ] A8. `/device` chứa object `pump` đầy đủ, JSON hợp lệ, không tràn buffer.
- [ ] A9. Bộ lệnh Serial hoạt động, không xung đột.
- [ ] A10. Comment trong code mô tả đúng code (không còn dẫn chiếu sai file nguồn/kênh LEDC).
- [ ] A11. Không còn tham chiếu treo tới `firmware/pump_l298n_xiao/` đã xoá trong tài liệu.
- [ ] A12. Biên dịch sạch bằng `arduino-cli` cho board AI Thinker ESP32-CAM.

## 11. Rủi ro còn lại (không xử lý trong phạm vi này)

- `fillDuty = 55%` là **giá trị ước lượng khởi điểm, không phải kết quả đo**. Phải dò lại trên bơm thật bằng lệnh `d`. L298N sụt ~1.8–2.5V nên bơm chỉ nhận ~9.5–10V.
- Nghiệm thu thực tế trên board vẫn cần làm tay; không có test tự động cho firmware này.

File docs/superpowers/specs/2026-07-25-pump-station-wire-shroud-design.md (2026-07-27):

# Thiết kế: Kênh giấu dây cho trạm bơm (pump_station v2)

**Ngày:** 2026-07-25
**Trạng thái:** Đã duyệt bởi user (phương án A), chờ viết plan triển khai.
**Liên quan:** [[pump-drive-decision]] (memory), `docs/superpowers/specs/2026-07-24-pump-station-mount-design.md` (spec v1 — vẫn là kiến trúc nền, doc này chỉ SỬA phần đi dây).

## Bối cảnh

`pump_station_001.scad` (spec 2026-07-24) đã in và lắp thử thật. Từ lần lắp đó,
user phản hồi 4 vấn đề cụ thể (không phải giả thuyết — quan sát trên phần cứng
thật, có ảnh):

1. **Khoang hộp L298N không tính thêm độ dài của driver**: khay dung sai hiện
   tại (`l298n_box_clr = 2.5mm` quanh 4 cạnh) không chừa đủ chỗ cho domino/
   terminal vít nhô ra mép board + bán kính bẻ dây xuống khe thoát — dây bị ép
   sát thành hộp.
2. **Yên kẹp bơm không có lối thoát dây theo thiết kế**: bơm RS365 thật có 2
   chân điện (tab đồng) nhô ra **ngang thân trụ động cơ, gần nắp đen** (không
   phải từ đầu trục như giả định ngầm) — ảnh thực tế cho thấy rõ. Khi lắp bơm
   theo chiều cần thiết để ngạnh ống hướng đúng ra khay, chân điện lại quay xa
   hộp L298N, dây phải vòng hở qua đỉnh cả 2 yên kẹp — xấu và không được thiết
   kế che.
3. **Không có gì che bó dây logic** (ENA/IN1/IN2/GND) chạy từ hộp L298N lên
   ESP32 gắn trên nắp ống quang học — lộ thiên hoàn toàn giữa 2 cụm tách rời
   (tách rời là chủ đích, để cách ly rung — xem `plan.md` §8).
4. **Toàn bộ khe/rãnh dây hiện có được tính theo dây trần** (mesh hở
   `wire_notch_w=6mm`, rãnh `wire_channel` rộng 6mm sâu 1.5mm). User dùng dây
   jumper đực-cái (không hàn) — mỗi đầu jumper là 1 khối nhựa nhỏ (~3×6mm),
   không lọt qua khe hẹp hoặc bị kẹt ở mép.

Người dùng đã xác nhận (qua hỏi-đáp trước khi viết spec này):
- **Giữ kiến trúc tách rời** ESP32 (trên nắp quang học) ↔ trạm bơm — không gộp
  điện tử vào 1 hộp. Chỉ cải thiện cách đi dây giữa 2 cụm.
- **Không hàn** — vẫn dùng jumper đực-cái, thiết kế phải chừa chỗ cho đầu nhựa.
- **Hướng lắp bơm linh hoạt cả 2 chiều** — không chốt cứng "chân điện luôn quay
  về phía hộp", vì thực tế đã cho thấy hướng đó xung đột với hướng ngạnh ống.

## Mục tiêu

Sửa `pump_station_001.scad` → `pump_station_002.scad` (bump version qua
`version-scad.sh pump_station`), chỉ đổi phần đi dây — **không đổi** cơ chế
kẹp bơm, cơ chế nắp hộp L298N, hay bố cục tổng (hộp ở đầu này, yên kẹp ở đầu
kia, nối bằng đế liền).

Sau khi sửa: dây (jumper hay trần) đi từ domino L298N tới bơm, và đầu dây logic
ra ESP32, đều nằm dưới 1 nắp che phẳng liền — nhìn từ trên xuống không thấy dây
nào, bất kể lắp bơm chiều nào.

## Kiến trúc

### 1. Kênh dây liền mạch mức thấp (thay rãnh ngắn hiện tại)

- `wire_channel()` hiện chỉ chạy đoạn hộp↔yên kẹp GẦN (`chan_len`). Kéo dài
  chạy SUỐT từ thành hộp L298N (cạnh OUT) tới hết mép ngoài yên kẹp XA —
  nghĩa là kênh chạy XUYÊN QUA bên dưới footprint của cả 2 khối yên kẹp (kênh
  cắt vào **đế**, ở z âm; khối yên kẹp là vật thể riêng đặt ĐÈ LÊN mặt đế từ
  z=0 trở lên — 2 vật thể không xung đột hình học vì khác dải z).
- Rộng ra từ 6mm → `wire_channel_w = 10.0mm`, đủ xếp 2-3 đầu jumper cạnh nhau.
  Sâu giữ `wire_channel_d = 2.0mm` (tăng nhẹ từ 1.5mm).
- 2 gờ ray dọc 2 bên miệng kênh (`wire_channel_rail`) để nắp đậy gài khớp nhựa
  dẻo (cùng cơ chế "PETG hơi dẻo ép giữ" đã dùng ở khe lồng bơm — không cần
  vít).
- **Nắp đậy kênh dây**: 1 thanh dài duy nhất, phẳng, dày ~2mm, dài suốt chiều
  dài kênh — chi tiết in RIÊNG (`print_pump_station_channel_cover_001.scad`).
  Tháo ra được để bảo trì/tháo bơm.

### 2. Khe nối lòng máng kẹp ↔ kênh dây (mới, ở yên kẹp)

- Mỗi yên kẹp (`pump_clamp_post()`) thêm 1 khe nhỏ xuyên qua bề dày đáy máng
  kẹp (`pump_clamp_t = 2.4mm`, đúng tại điểm thấp nhất của lòng máng — đã là
  điểm mỏng nhất theo thiết kế đối xứng trên/dưới của v1), nối lòng máng với
  mặt đế ngay phía trên kênh dây bên dưới. Kỹ thuật giống hệt `wire_notch` đã
  dùng trong `l298n_box_walls()` (khe xuyên thành tại mức sàn) — tái dùng
  pattern có sẵn, không phát minh cơ chế mới.
- Vì lòng máng là hình trụ, bơm xoay tự do trước khi ép xuống từ khe lồng
  trên đỉnh (khe lồng hiện có, không đổi) — user chỉnh chân điện của bơm
  hướng xuống khe mới này lúc lắp, bất kể ngạnh ống hướng ra +X hay −X.
- **Chưa chốt kích thước chính xác khe này** (`pump_clamp_wire_notch_w/h`) —
  sẽ tinh chỉnh bằng render preview lúc triển khai (`/preview-scad`), vì phụ
  thuộc khớp nối hình học 3D giữa mặt cong lòng máng và mặt phẳng đế mà mô tả
  bằng lời không đủ chính xác.

### 3. Hộp L298N — nới khoang 2 cạnh có domino

- Đổi `l298n_box_clr` (1 hằng số dùng chung 4 cạnh) thành 2 hằng số riêng:
  - `l298n_box_clr_x = 8.0mm` — cạnh dọc trục X (cạnh IN 12V ở −X, cạnh OUT
    động cơ ở +X) — đây là 2 cạnh có domino vít nhô ra, cần chỗ bẻ dây.
  - `l298n_box_clr_y = 4.0mm` — cạnh dọc trục Y (cạnh LOGIC + cạnh thoát khí)
    — tăng nhẹ so 2.5mm cũ, đủ cho đầu jumper logic nhưng không lãng phí
    nhựa như cạnh X.
  - Hộp từ hình vuông 52×52mm → hình chữ nhật `l298n_box_od_l ≈ 63mm ×
    l298n_box_od_w ≈ 55mm`. Nắp hộp (`pump_station_lid()`) tự động khớp theo
    vì dùng chung các hằng số `l298n_box_od_*` — không cần đổi thiết kế nắp,
    chỉ regenerate theo kích thước mới.
- Khe dây LOGIC (cạnh +Y) nới từ `wire_notch_w=6mm` → hằng số riêng
  `wire_notch_logic_w = 14.0mm`, `wire_notch_logic_h = 6.0mm` — đủ ôm 3-4 đầu
  jumper (ENA, IN1, IN2, GND) xếp cạnh nhau. Khe IN(12V)/OUT(động cơ) giữ
  `wire_notch_w/h` cũ (6/5mm) — 2 khe này chủ yếu là dây trần/đầu cosse vào
  domino vít, không phải đầu jumper nhựa, không cần nới rộng miệng khe (vấn đề
  của chúng là THIẾU CHỖ BẺ DÂY bên trong hộp, đã giải quyết bằng
  `l298n_box_clr_x`, không phải miệng khe hẹp).
- Thêm 1 gờ neo bó dây nhỏ (trụ tròn `l298n_wire_anchor_d = 6mm`, cao bằng
  `wire_notch_logic_h`) ngay bên ngoài khe LOGIC, cách thành hộp ~8mm — dây ra
  ESP32 vòng qua gờ này 1 lần trước khi đi tự do, tránh lực kéo trực tiếp vào
  chân cắm trên board.

### 4. Ghi chú lắp ráp (không phải hình học in — ghi vào tài liệu lắp ráp)

- Bó 3-4 dây logic ra ESP32 bằng ống gen xoắn (spiral wrap) hoặc ống gen mềm,
  đoạn từ gờ neo tới ESP32 — biến dây rời thành 1 bó gọn. Việc này nằm ngoài
  phạm vi in 3D.

## File / constants cần thêm hoặc sửa

- Mới: `openscad/components/pump_station_002.scad` — dựng bằng
  `.claude/skills/openscad/scripts/version-scad.sh pump_station` (kế thừa
  toàn bộ `pump_station_001.scad`, sửa `l298n_box_walls()`, `wire_channel()`,
  `pump_clamp_post()`; thêm module `pump_station_wire_cover()`).
- Mới: `openscad/print/print_pump_station_002.scad` (đế+hộp+yên, kế thừa
  `print_pump_station.scad` trỏ sang file component mới).
- Mới: `openscad/print/print_pump_station_channel_cover_001.scad` (chi tiết
  nắp che kênh dây, in riêng — thứ 3 cùng bộ với đế+hộp và nắp hộp L298N).
- `print_pump_station_lid.scad` (nắp hộp L298N) — regenerate theo kích thước
  hộp mới (`l298n_box_od_l/w` đổi), KHÔNG đổi thiết kế cơ chế nắp.
- Sửa `openscad/constants.scad` (cạnh block `l298n_*`/`pump_clamp_*`/
  `pump_station_*` hiện có, dòng ~169-218):
  - Đổi `l298n_box_clr` → 2 hằng số `l298n_box_clr_x = 8.0`,
    `l298n_box_clr_y = 4.0`.
  - Thêm `wire_notch_logic_w = 14.0`, `wire_notch_logic_h = 6.0`.
  - Thêm `l298n_wire_anchor_d = 6.0`.
  - Đổi `wire_channel` liên quan: `wire_channel_w = 10.0` (thay tên khỏi biến
    cục bộ `ch_w=6.0` trong module cũ, đưa lên constants.scad),
    `wire_channel_d = 2.0`, `wire_channel_rail_w = 2.0`,
    `wire_channel_rail_h = 1.5`.
  - Thêm `pump_clamp_wire_notch_w`, `pump_clamp_wire_notch_h` — giá trị khởi
    điểm đề xuất `4.0` / `pump_clamp_t + 2.0`, **sẽ chỉnh lại theo preview**
    (xem ghi chú ở mục 2 Kiến trúc).
  - Dẫn xuất `l298n_box_id_l/w`, `l298n_box_od_l/w`,
    `pump_station_len/wid` — sửa công thức dùng `l298n_box_clr_x/y` thay
    `l298n_box_clr` (các assert hiện có ở dòng ~379-389 giữ nguyên logic,
    chỉ đổi biến tham chiếu).

## Không làm trong thiết kế này

- Không đổi cơ chế kẹp bơm (khe lồng từ trên, ép PETG dẻo) hay cơ chế nắp hộp
  L298N (vít M3 tự-ren 2 góc chéo) — 2 đã hoạt động tốt theo phản hồi lắp thật,
  chỉ vấn đề nằm ở phần đi dây.
- Không thiết kế giắc DC barrel jack tích hợp — ảnh thực tế cho thấy user đã
  tự dùng 1 domino xanh (pluggable terminal) làm adapter DC-jack→dây trần rồi
  cắm vào domino 12V của L298N; domino xanh đó nằm NGOÀI hộp in, không thuộc
  phạm vi thiết kế này.
- Không gộp ESP32/adapter 12V vào chung hộp với L298N (đã hỏi và user chọn giữ
  tách rời).
- Không thiết kế conduit/ống gen cứng nối 2 cụm (ống gen mềm là giải pháp lắp
  ráp, không phải chi tiết in).

## Giả định cần xác nhận sau (không chặn triển khai, gắn cờ trong code)

1. Kích thước chính xác board L298N thật vẫn CHƯA ĐO (kế thừa từ spec v1) —
   `l298n_box_clr_x/y` mới là ước tính dựa trên quan sát ảnh domino nhô ra, có
   thể cần chỉnh lại khi đo board thật.
2. Vị trí chính xác 2 chân điện trên thân bơm (khoảng cách từ nắp đen, góc
   quay) chưa đo bằng số — thiết kế khe nối lòng máng↔kênh dây ở mục Kiến
   trúc §2 chấp nhận sai số bằng cách để lòng máng xoay tự do, không cần biết
   góc chính xác.
3. `pump_clamp_wire_notch_w/h` là giá trị khởi điểm, sẽ chỉnh qua preview-scad
   lúc triển khai thực tế.

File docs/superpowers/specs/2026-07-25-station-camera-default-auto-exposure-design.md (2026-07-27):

# Thiết kế: Trả mặc định camera trạm (aqua_scope_station) về auto exposure

**Ngày:** 2026-07-25
**Trạng thái:** Đã duyệt bởi user, chờ viết plan triển khai.
**Liên quan:** [[image-processing-hybrid]] (memory), `firmware/aqua_scope_station/README.md`, `docs/superpowers/specs/2026-07-19-aqua-scope-station-firmware-design.md` (spec gốc dựng file này — doc này chỉ SỬA hành vi mặc định camera, không đổi kiến trúc).

## Bối cảnh

`aquaPrefsApplyDefaults()` (`firmware/aqua_scope_station/aqua_prefs.cpp`) ép
cứng AEC / AEC-DSP / AGC **tắt** và một mức phơi sáng thủ công tối
(`aec_value=100`, `agc_gain=0`) mỗi lần board boot **và** mỗi lần gọi
`/control?var=reset`. Hàm này chạy TRƯỚC khi `aquaPrefsLoad()` nạp cấu hình đã
lưu (nếu có), nên đây luôn là trạng thái camera đầu tiên người dùng nhìn thấy.

Hệ quả: ảnh mặc định tối, khó ngắm/chỉnh, và mỗi phiên làm việc phải tự bật lại
AEC/AGC qua web UI rồi mới chỉnh tiếp — kể cả khi chỉ đang thử nghiệm, không
chụp đo thật.

`firmware/aqua_scope_cam/aqua_scope_cam.ino` (firmware camera-only tiền đề của
trạm) đã được sửa trước đó để KHÔNG ép AEC/AGC tắt — `applyConfig()` của file
đó chỉ set brightness/contrast/special_effect/mirror/flip/quality, để sensor tự
chạy auto exposure/gain mặc định của nó. Đây chính là hành vi "các firmware
khác" mà user muốn `aqua_scope_station` khớp theo.

**Xác nhận với user trước khi viết doc này:**
- Chỉ đổi **mặc định lúc boot/reset**. Khả năng chỉnh tay sang chế độ
  backlit/manual (tắt AEC/AGC, đặt exposure/gain) qua `/control?var=aec` v.v.
  (đã có sẵn trong `app_httpd.cpp`) giữ nguyên — vẫn cần dùng nó trước khi chụp
  đo hạt thật.
- Cập nhật luôn comment/README trong thư mục firmware cho khớp hành vi mới.
- Cập nhật luôn đoạn liên quan trong CLAUDE.md gốc (mục "Lighting").

## Mục tiêu

Sau khi sửa: cấp điện lần đầu (chưa từng `save`) hoặc gọi `?var=reset` →
camera ở trạng thái auto exposure/gain bình thường như CameraWebServer gốc,
ảnh sáng và ngắm được ngay. Muốn chụp đo backlit thật thì người vận hành tự
tắt AEC/AGC + chỉnh tay qua web UI/serial rồi `?var=save` như quy trình hiện
có — không đổi phần này.

## Thay đổi mã nguồn

### `aqua_prefs.cpp` — `aquaPrefsApplyDefaults()`

Xoá 5 dòng ép tắt auto và đẩy giá trị thủ công tối:

```cpp
s->set_exposure_ctrl(s, 0);  // AEC off
s->set_aec2(s, 0);           // AEC-DSP off
s->set_gain_ctrl(s, 0);      // AGC off
s->set_aec_value(s, DEF_AEC_VALUE);
s->set_agc_gain(s, DEF_AGC_GAIN);
```

Giữ nguyên các dòng còn lại của hàm (`set_contrast`, `set_brightness`,
`set_quality`, `set_framesize` qua `clampFramesize`, `set_hmirror`,
`set_vflip`) — các thông số này không liên quan tới vấn đề "tối/khó chỉnh".

Không gọi `set_exposure_ctrl`/`set_aec2`/`set_gain_ctrl` với giá trị `1` để ép
bật — để trống, y hệt cách `aqua_scope_cam.ino` làm: sensor tự giữ trạng thái
auto mà driver `esp_camera_init()` đã thiết lập sẵn (đúng behavior của bản
CameraWebServer gốc).

Hằng số `DEF_AEC_VALUE`, `DEF_AGC_GAIN` **giữ lại** — vẫn dùng làm giá trị dự
phòng trong `aquaPrefsLoad()` khi đọc NVS thiếu key `aec_value`/`agc_gain`
(trường hợp phòng thủ, không phải đường chạy chính).

### Không đổi

- `aquaPrefsLoad()` — khi flash đã có cấu hình lưu (`saved=true`), tức người
  dùng đã chủ động chỉnh + bấm `?var=save` trước đó, hàm này vẫn nạp và áp
  đúng y những gì đã lưu (kể cả nếu đó là cấu hình backlit/manual). Đây là
  đường "chỉnh 1 lần dùng mãi" đúng như thiết kế ban đầu, không phải thứ đang
  gây khó chịu.
- `app_httpd.cpp` — các endpoint `/control?var=aec|aec2|agc|aec_value|agc_gain`
  giữ nguyên toàn bộ.
- Bơm, WiFi, watchdog, `/device`, `/status` — ngoài phạm vi.

## Tài liệu cần cập nhật theo

1. `firmware/aqua_scope_station/README.md`
   - Mục "Khác gì bản CameraWebServer gốc", điểm 1: đổi từ "Mặc định backlit —
     tắt AEC/AEC-DSP/AGC..." sang mô tả mặc định là auto exposure như bản gốc;
     backlit/manual là bước người vận hành tự bật trước khi đo.
   - Dòng bảng endpoint `?var=reset`: bỏ chữ "về mặc định backlit", thay bằng
     "xoá cấu hình đã lưu, về mặc định auto exposure (như bản gốc)".
2. `aqua_scope_station.ino` — comment đầu file, mục "Khác bản CameraWebServer
   gốc đúng 3 điểm", điểm 1: cập nhật tương tự.
3. `aqua_prefs.h` — comment đầu file và comment trên khai báo
   `aquaPrefsApplyDefaults()`: bỏ mô tả "áp bộ mặc định backlit silhouette",
   thay bằng mô tả mặc định auto + ghi rõ manual backlit là cấu hình người
   dùng tự chỉnh/lưu.
4. `aqua_prefs.cpp` — comment khối "Mặc định backlit silhouette" phía trên
   các hằng `DEF_*`: cập nhật cho khớp (không còn ép AEC/AGC tắt mặc định).
5. `CLAUDE.md`, mục "Lighting is backlit silhouette...": giữ nguyên yêu cầu
   vật lý (phải tắt AEC/AGC + đặt exposure thấp **trước khi chụp khung phân
   tích**), nhưng làm rõ đây không còn là trạng thái mặc định lúc cấp điện —
   là bước người vận hành (hoặc script tự động sau này) phải chủ động bật qua
   web UI/serial rồi lưu, giống các firmware camera khác trong repo.

## Kiểm thử / nghiệm thu

Không có test tự động cho firmware (nạp qua Arduino IDE, kiểm bằng board
thật). Bổ sung 1 mục vào checklist "Nghiệm thu trên board thật" của README:

- [ ] Cấp điện lần đầu (chưa từng `?var=save`) → mở `http://<ip>/` → ảnh sáng
      bình thường (không phải mảng xám tối cháy contrast), slider AEC/AGC ở
      trạng thái ON.
- [ ] `?var=reset` khi đang ở cấu hình đã lưu → về lại đúng trạng thái auto ở
      trên (không quay lại dark cũ).
- [ ] Tắt AEC/AGC + chỉnh tay qua web UI như quy trình canh sáng backlit hiện
      có → `?var=save` → rút điện → cắm lại → đúng cấu hình backlit đã lưu
      (không bị ghi đè bởi default auto).

Không cần thêm test nào khác — đây là thay đổi phạm vi hẹp, không đụng tới
logic bơm/WiFi/lưu trữ.

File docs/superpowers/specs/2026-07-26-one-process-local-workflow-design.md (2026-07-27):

# Thiết kế: Gộp workflow local về một tiến trình + chạy suy luận liên tục

**Ngày:** 2026-07-26
**Trạng thái:** Đã duyệt bởi user, chờ viết plan triển khai.
**Nhánh:** `feature/simple-local-workflow`
**Liên quan:** `docs/superpowers/specs/2026-07-14-web-system-design.md` (hệ web gốc),
`docs/superpowers/specs/2026-07-15-branch1-pc-inference-design.md` (pipeline `ml/infer`),
`docs/superpowers/specs/2026-07-19-aqua-scope-station-firmware-design.md` (firmware trạm),
`docs/superpowers/specs/2026-07-25-station-camera-default-auto-exposure-design.md`
(quyết định KHÔNG ép darkmode mặc định — doc này tôn trọng, xem §2.4).

## Bối cảnh

Để chạy được một lượt đo hiện phải làm 6 bước tay, trên 3 mặt phẳng điều khiển
khác nhau (Serial Monitor, curl, 2 cửa sổ terminal):

| # | Bước | Ở đâu |
|---|---|---|
| 1 | Nạp firmware, mở Serial Monitor 115200 lấy IP | Arduino IDE |
| 2 | `curl "http://<ip>/control?var=darkmode&val=1"` rồi `?var=save` | terminal |
| 3 | `curl "http://<ip>/control?var=pump_auto&val=1"` | terminal |
| 4 | `cd web/backend && python -m uvicorn app.main:app --port 8000` | terminal A |
| 5 | `python -m ml.infer --from-board <ip> --count 5 --interval 2` | terminal B |
| 6 | Mở `http://localhost:8000` | trình duyệt |

Hai vấn đề user nêu:

1. **Rườm rà.** Không có "một nút bật", và mọi tham số (IP board, số khung, chu
   kỳ) đều nằm rải rác giữa cờ CLI và `ml/config.local.toml`.
2. **Không suy luận liên tục.** `Esp32CaptureSource.frames()`
   (`ml/infer/source.py:151`) chạy `for i in range(self.count)` rồi trả về —
   `--count 5` nghĩa là đúng 5 khung rồi CLI thoát. Muốn đo tiếp phải gõ lại
   lệnh. Nguyên nhân gốc: class này trộn *cách nói chuyện với board* (đọc
   `/device`, GET `/capture`, retry) vào *vòng lặp đếm N khung*, nên không có
   cách nào lấy "một khung theo yêu cầu".

## Mục tiêu

Sau khi sửa: bật `start.bat` → trình duyệt mở `http://localhost:8000` → gõ/dò IP
board một lần → bấm **Bắt đầu** → hệ thống tự chụp + suy luận theo từng chu kỳ
bơm, **không giới hạn số khung**, cho tới khi bấm **Dừng**. Không mở terminal
thứ hai, không sửa file config để đổi tham số vận hành.

## Quyết định đã chốt với user

| Câu hỏi | Chốt |
|---|---|
| Điều khiển ở đâu | **Nút trên dashboard.** Vòng lặp chạy như worker thread trong backend web |
| Cái gì kích hoạt một lần chụp | **Cạnh pha bơm SETTLING** đọc từ `/device`, không phải interval cố định |
| Chạy liên tục có làm ngập sổ audit không | **Hai chế độ XEM / ĐO.** XEM = infer live, không ghi gì. ĐO = ghi đủ vào sổ audit |
| Tìm IP board thế nào | **mDNS (`aqua-scope.local`) + ô nhập tay trên web**, lưu lại cho lần sau |

---

## 1. Kiến trúc

Một tiến trình duy nhất:

```
start.bat
  └── python -m uvicorn --app-dir web/backend app.main:app   (cwd = gốc repo)
        ├── FastAPI
        │     ├── dashboard + /api/ingest + /api/samples      (đã có)
        │     └── /api/runner/* + /api/station/* + /api/settings   (MỚI)
        └── Runner thread (MỚI)
              poll /device 0.5s → thấy cạnh vào SETTLING → chờ capture_delay
              → GET /capture → detector → (ĐO) POST /api/ingest của chính mình
```

### 1.1 Vì sao runner POST ngược vào `/api/ingest` thay vì ghi thẳng DB

Ingest hiện có (`web/backend/app/routers/ingest.py`) đã cầm 4 thứ khó: validate
payload, sinh `sample_code` khi thiếu, idempotency theo `sample_code`, và ghi
**nguyên tử** (row sample + rows particle + file ảnh cùng sống hoặc cùng chết).
Ghi thẳng DB từ runner nghĩa là chép lại cả 4 thứ đó, và mọi sửa đổi sau này
phải sửa hai nơi — đúng kiểu bug âm thầm mà sổ audit không được phép có.

Chi phí: một vòng HTTP qua loopback cho mỗi mẫu (~vài ms so với ~1–3s tải ảnh
UXGA qua WiFi). Không đáng kể.

Hệ quả tốt kèm theo: `ml.infer` CLI **không đổi hành vi** — nó vẫn là một client
HTTP như trước, chạy độc lập được cho việc chạy lại thư mục ảnh.
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

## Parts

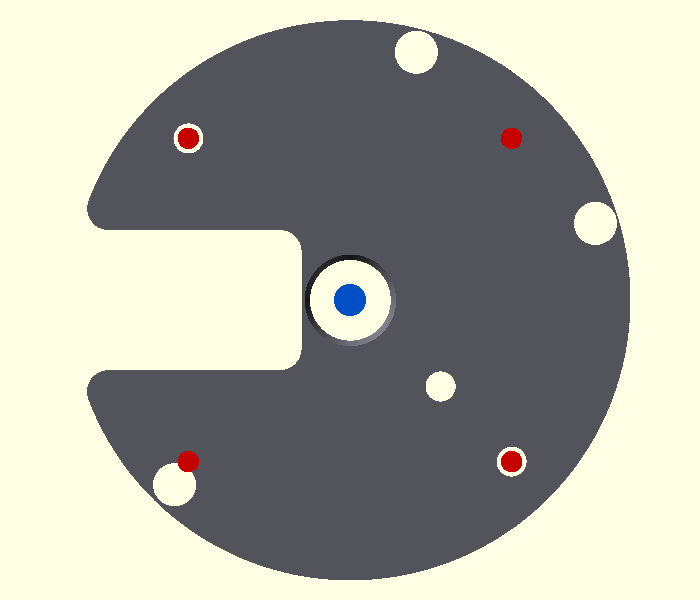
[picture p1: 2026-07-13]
openscad/components/top_cap_002_bottom.png

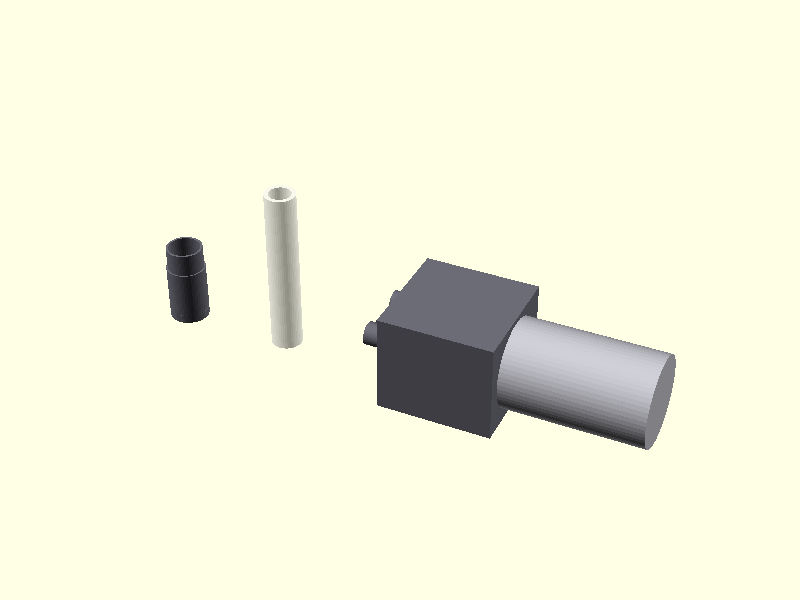
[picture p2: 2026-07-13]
openscad/components/accessories_001.png

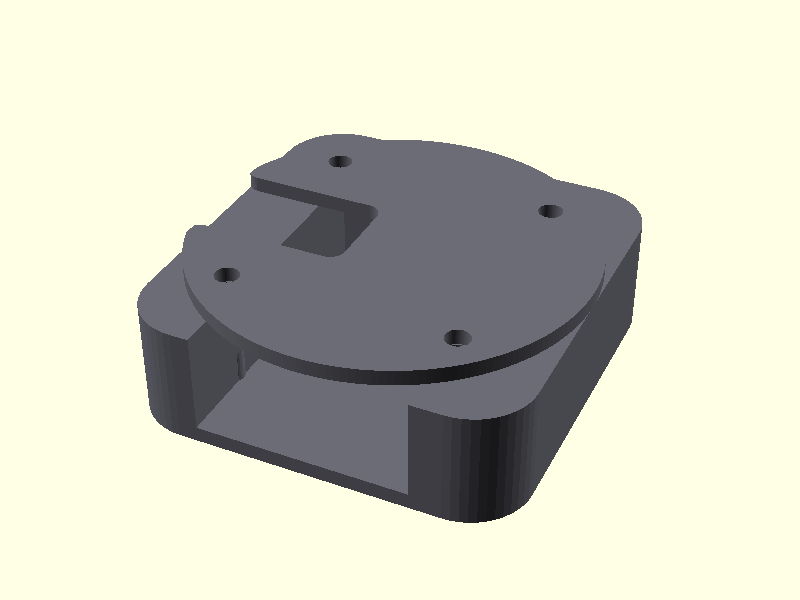
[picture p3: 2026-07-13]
openscad/components/top_cap_esp32cam_001.png

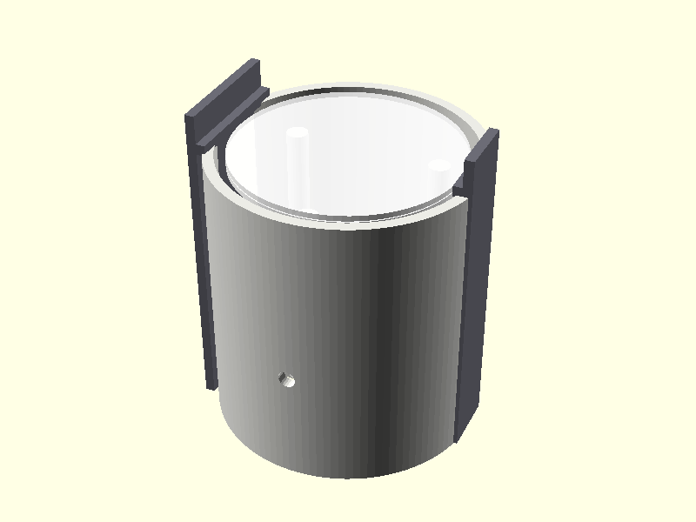
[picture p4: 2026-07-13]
openscad/components/light_box_002.png

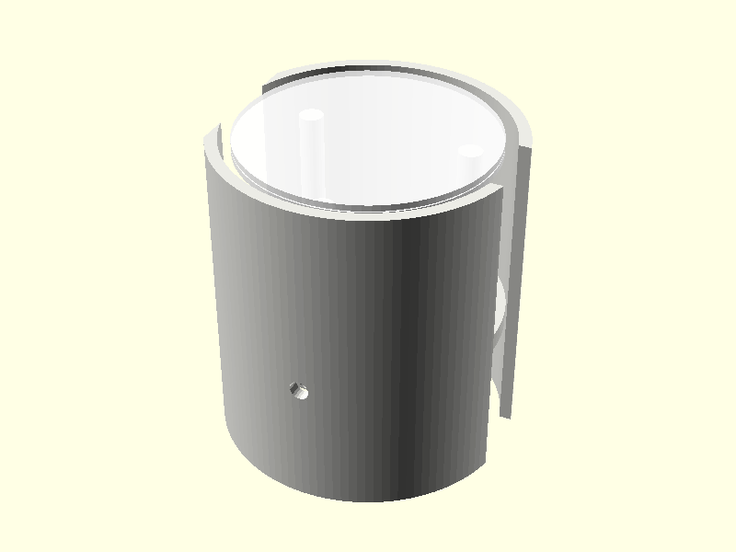
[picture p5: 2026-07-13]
openscad/components/light_box_001.png

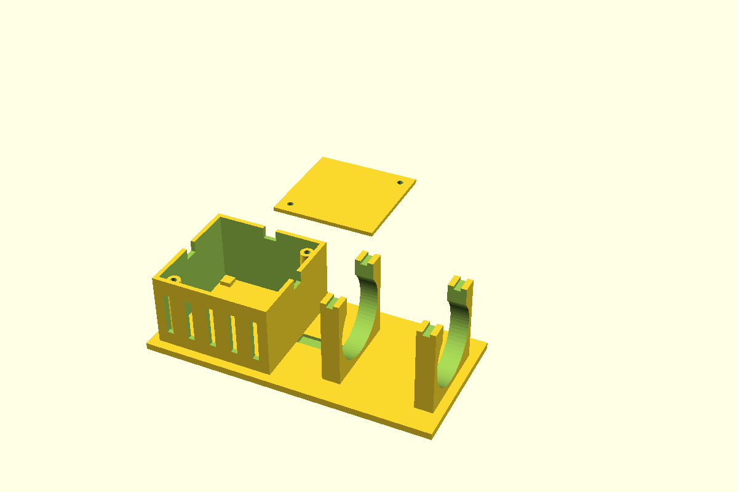
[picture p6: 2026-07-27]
openscad/components/pump_station_001.png

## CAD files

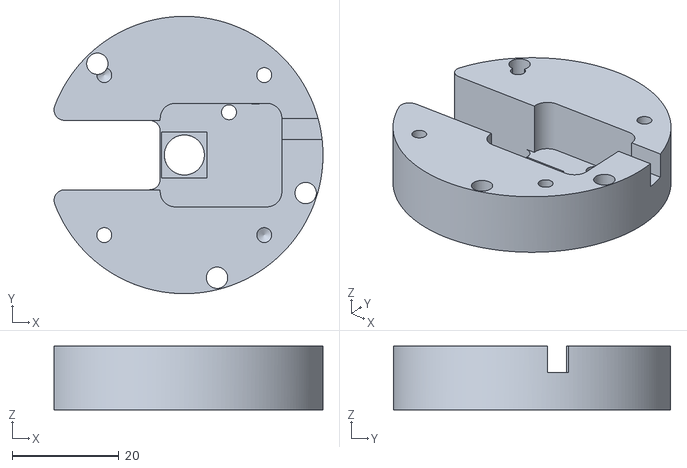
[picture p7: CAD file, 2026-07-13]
base/Assembly_Matchboxscope_injectionmolded_xiao_IM_Matchboxscope_base_xiao_9.stl
50.5 x 52.0 x 12.0

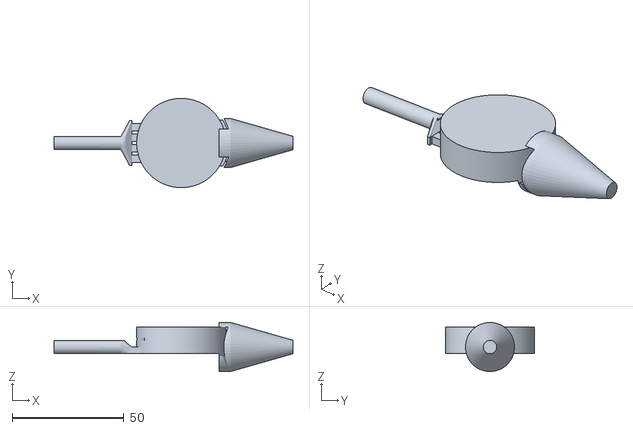
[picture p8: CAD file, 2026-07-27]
openscad/verify/fluid_domain_full_001.stl
107.1 x 40.0 x 22.0

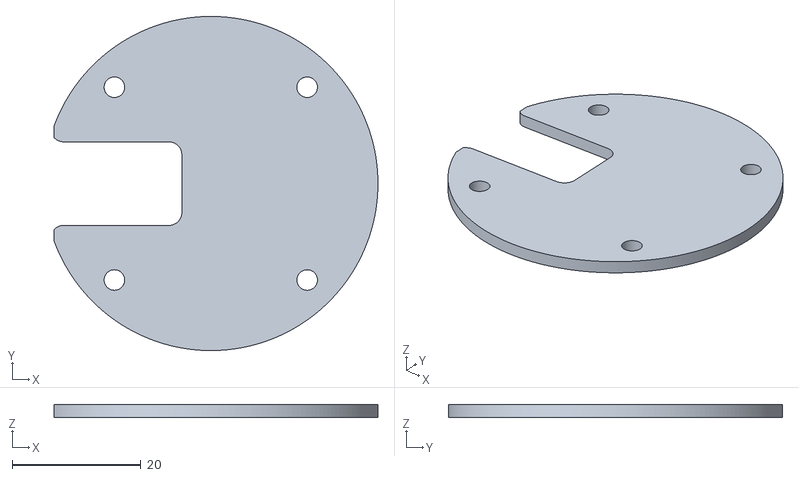
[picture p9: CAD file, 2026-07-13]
base/Assembly_Matchboxscope_injectionmolded_xiao_IM_Matchboxscope_base_xiao_lid_10.stl
50.4 x 52.0 x 2.00

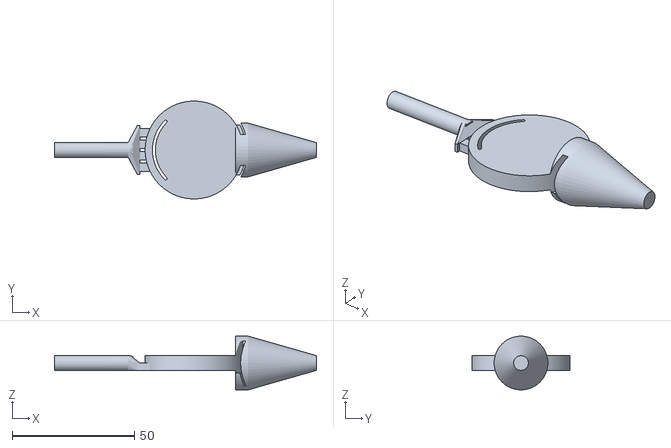
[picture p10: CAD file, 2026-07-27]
openscad/verify/fluid_domain_001.stl
107.1 x 40.0 x 22.0

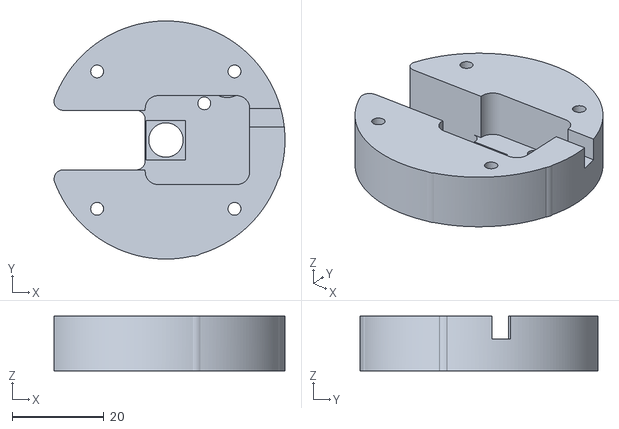
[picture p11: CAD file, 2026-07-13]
openscad/print/black/print_top_cap_xiao.stl
50.5 x 52.0 x 12.0

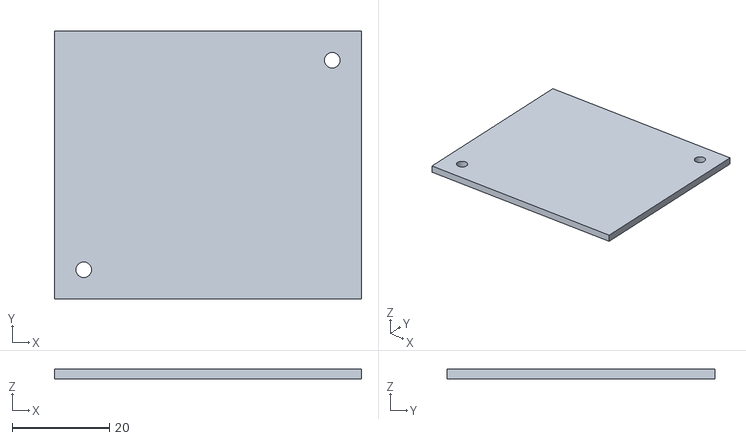
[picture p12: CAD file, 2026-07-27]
openscad/print/print_pump_station_lid.stl
63.0 x 55.0 x 2.00

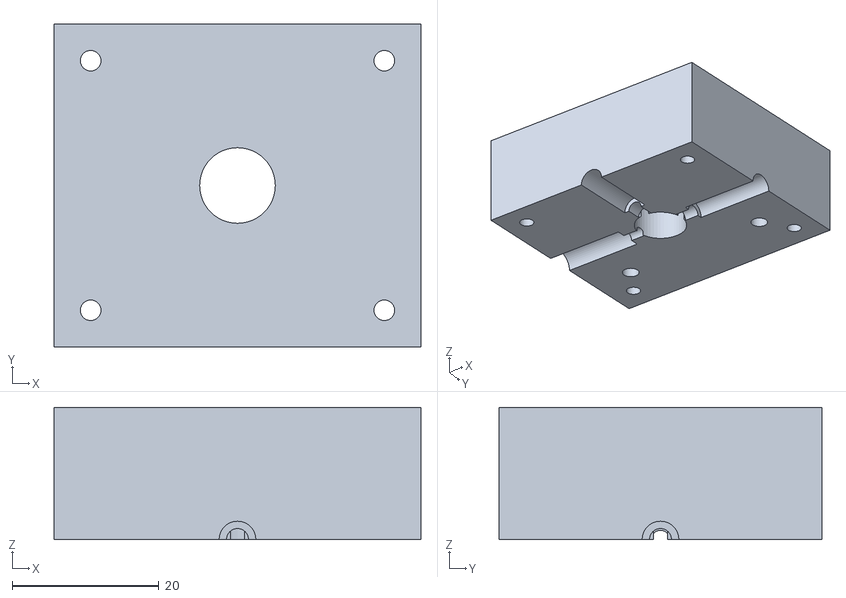
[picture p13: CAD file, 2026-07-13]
variants/openscad_1d/print/print_block_lower.stl
50.0 x 44.0 x 18.0

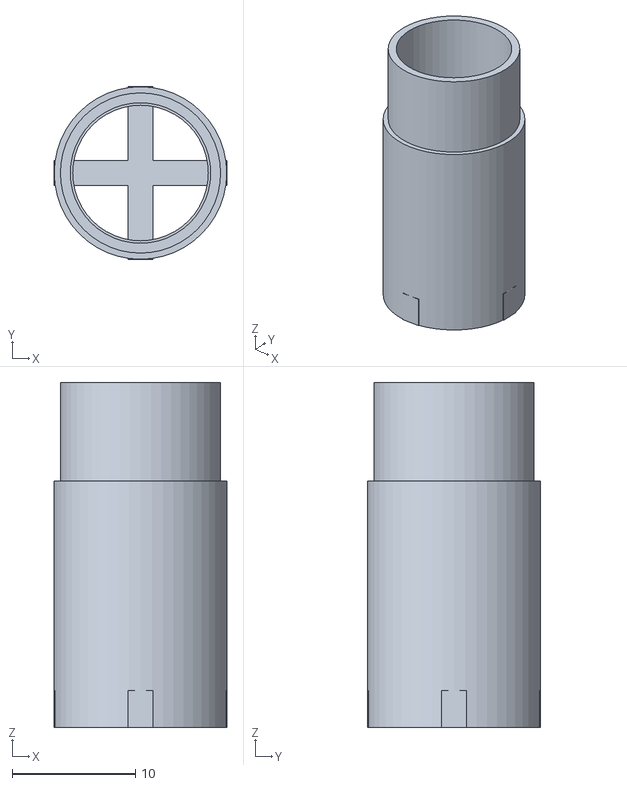
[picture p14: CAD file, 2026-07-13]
openscad/print/black/print_prescreen.stl
14.0 x 14.0 x 28.0

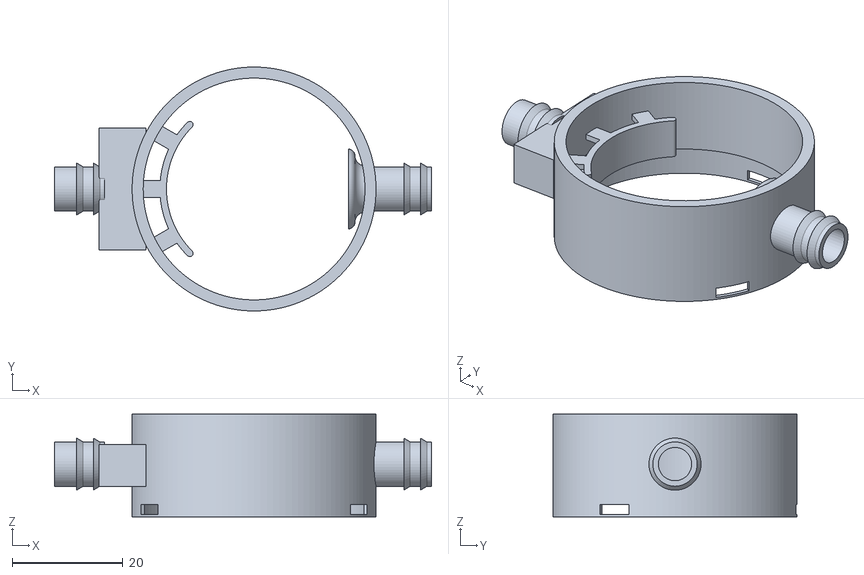
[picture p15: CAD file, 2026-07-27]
openscad/print/print_flow_tray.stl
68.0 x 44.0 x 18.5

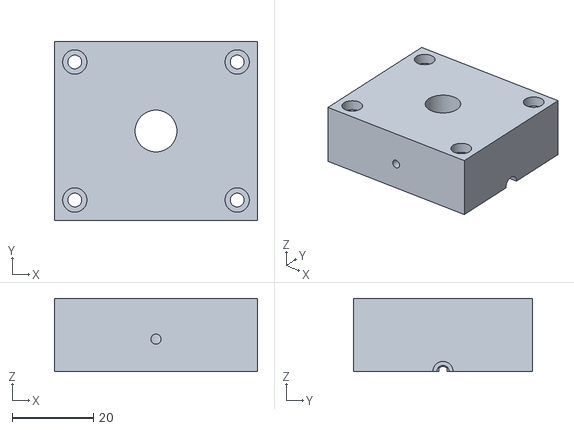
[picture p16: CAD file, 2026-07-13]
variants/openscad_1d/print/print_block_upper.stl
50.0 x 44.0 x 18.0

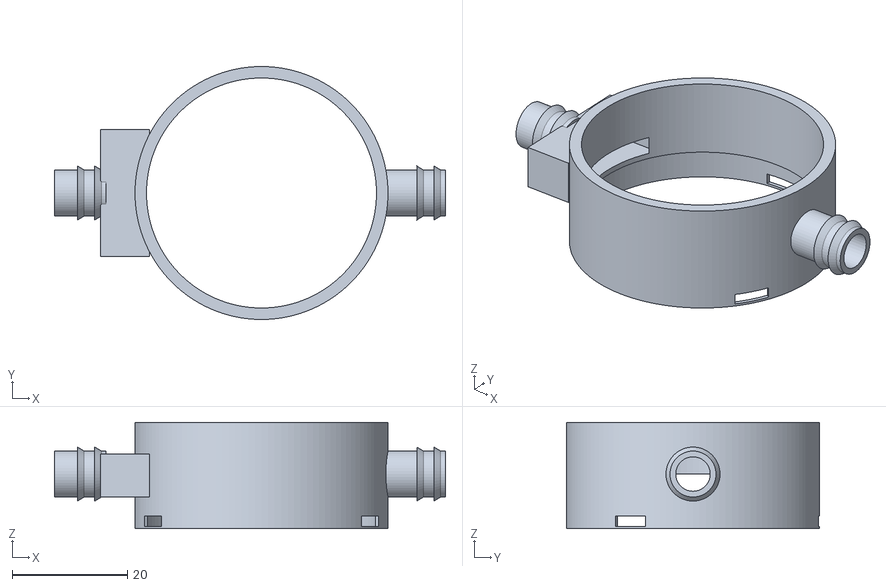
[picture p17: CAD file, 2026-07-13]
openscad/print/black/print_flow_tray.stl
68.0 x 44.0 x 18.5

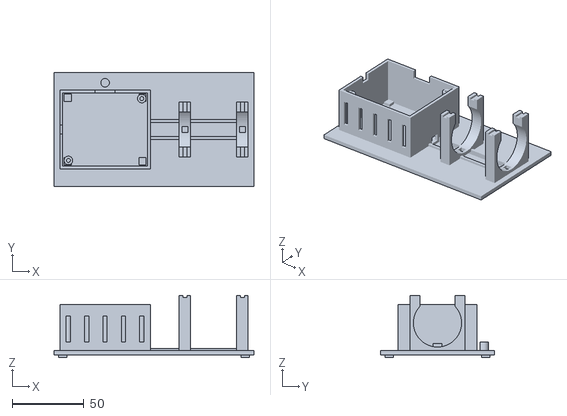
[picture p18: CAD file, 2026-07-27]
openscad/print/print_pump_station.stl
139.0 x 79.0 x 43.3

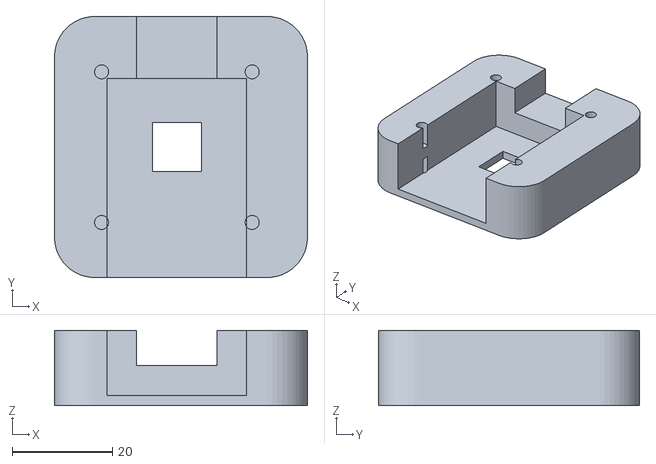
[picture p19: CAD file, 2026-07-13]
openscad/print/black/print_top_cap_esp32cam.stl
50.4 x 52.0 x 15.0

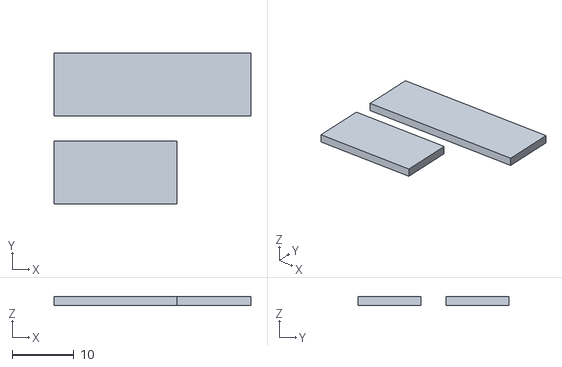
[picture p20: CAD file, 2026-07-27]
openscad/print/print_pump_station_channel_cover.stl
32.0 x 24.6 x 1.50

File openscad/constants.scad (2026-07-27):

// ============================================================================
// constants.scad — Aqua Scope (baseline "Backlit Silhouette")
// ----------------------------------------------------------------------------
// TOÀN BỘ hằng số của hệ. KHÔNG chứa geometry (chỉ helper module dùng chung).
// Nguồn: plan.md §5#2, implementation_plan.md §"Bảng Hằng Số Baseline",
//        technical_specs.md (đo STL), các quyết định G1–G5 (plan.md §2).
//
// HỆ TRỤC CHUNG (assembly):
//   - Gốc O = TÂM QUANG HỌC tại MẶT SÀN KHAY (mặt trên đĩa acrylic đáy).
//   - Trục Z = trục quang; +Z hướng LÊN camera.
//   - Nước: z = 0 .. water_depth (mặt nước z = water_depth).
//   - Ống kính camera: z = water_depth + work_dist (= 46 danh nghĩa).
//   - Mỗi component có gốc cục bộ riêng tiện dựng; assembly chịu trách nhiệm đặt.
// ============================================================================

// ---------------------------------------------------------------- Dung sai / in
tol        = 0.2;   // dung sai FDM tiêu chuẩn (khe lắp trượt mỗi bên)
wall_t     = 2.0;   // bề dày tường mặc định
fit_clr    = 0.4;   // dung sai lỗ cắm ma sát (lỗ module LED qua vách) — G5

// ---------------------------------------------------------------- Quang học
work_dist  = 40.0;  // cự ly ống kính ↔ MẶT NƯỚC (đo thật: nét 3–5cm → chọn 40)
fov_w_est  = 46.0;  // FOV ngang ước lượng tại work_dist (~46mm)

// ---------------------------------------------------------------- XIAO ESP32-S3 Sense
xiao_l     = 21.0;  // dài PCB
xiao_w     = 17.8;  // rộng PCB
xiao_h     = 2.5;   // dày PCB
xiao_cam_d = 8.0;   // Ø ống kính camera (cảm biến OV3660 — KHÔNG phải OV2640)

// ---------------------------------------------------------------- Nắp trụ = base Matchboxscope ĐÃ IN (tái dùng, KHÔNG dựng mới)
cap_l          = 50.45; // footprint base (X) — technical_specs.md
cap_w          = 52.0;  // footprint base (Y)
cap_h          = 12.0;  // chiều cao base
cam_aperture   = 7.5;   // Ø lỗ camera THẬT ở tâm base (đo STL)
// Giao diện lắp M3 (đo lại STL bằng trimesh 2026-07-07):
mount_pitch    = 30.0;            // bước lỗ vuông 30×30
mount_center   = [-6.2, 81.5];    // tâm cụm lỗ = TRỤC QUANG (toạ độ STL gốc!)
                                  // (lệch ~0.8mm so tâm outline −5.39 — căn theo TRỤC QUANG)
mount_hole_base_d = 2.8;  // lỗ TỰ-REN M3 trên base (vít bắt vào đây)
mount_hole_lid_d  = 3.2;  // lỗ THÔNG M3 (clearance) trên chi tiết đối ứng (bích ống)
// ⚠️ 3 lỗ Ø8 quanh lỗ camera trong STL là DI SẢN Matchboxscope — BỎ QUA, không tái tạo.

// ---------------------------------------------------------------- Thân trụ (ống THẲNG — G2: 1 ống liền suốt)
tube_od    = 50.0;  // ≤ 50.45 (cạnh ngắn base) để base phủ kín miệng — KHÔNG phình cốc
tube_wall  = 2.0;
tube_id    = tube_od - 2*tube_wall;  // = 46, ≥ nón FOV ~46 tại work_dist
tube_h     = 45.0;  // đoạn quang học (bích đỉnh → gờ kê khay), ≈ work_dist + margin

// ---------------------------------------------------------------- Khay dòng chảy (Macro-Flow, thiết kế MỚI — KHÔNG chi tiết giữ hạt)
tray_inner   = 40.0;  // Ø vùng nước ảnh hóa (lấp ~87% khung)
tray_wall    = 2.0;
tray_outer   = tray_inner + 2*tray_wall;  // = 44, lọt tube_id=46 có khe
tray_depth   = 12.0;  // chiều cao thành khay trên sàn (> mực nước)
water_depth  = 6.0;   // mực nước khi settle (giữ bằng van bơm tự chặn) — CHƯA CHỐT 5/6, tham số
inlet_slot_w = 20.0;  // cổng VÀO: khe khuếch tán ~20×3 SÁT ĐÁY (tia → màng rộng)
inlet_slot_h = 3.0;
outlet_barb_od = 8.0; // cổng RA: ngạnh OD=8 SÁT ĐÁY (G4: 8mm là OD cổng bơm — dùng chung cỡ)
outlet_bore    = 6.0; // lòng chảy trong ngạnh (~6 ≥ 3× hạt 2mm)
fillet_r     = 2.5;   // bo góc đáy–thành ≥2.5 (chống đọng)
// port_layout: VÀO ↔ RA đối tâm 180° (VÀO tại −X, RA tại +X trong hệ khay)
weir_h       = 6.0;   // mép tràn TÙY CHỌN (chặn-tràn an toàn) — không bắt buộc
drain_port_d = 8.0;   // van xả đáy TÙY CHỌN (vệ sinh) — không thuộc chu trình

// ---------------------------------------------------------------- CHỐNG SÓNG (2026-07-23)
// Nguồn: docs/research/2026-07-23-khay-lang-song-nghien-cuu-hop-nhat.md
// ⚠️ 4 số dưới đây LỆCH CÓ CHỦ Ý so với tài liệu nghiên cứu — lý do ghi tại chỗ.
particle_max = 2.0;    // hạt lớn nhất trong phạm vi test (CLAUDE.md: <2mm)

// (e) Cửa vào ĐỤC LỖ — thay khe hở liền 20×3 bằng N cửa sổ ngăn bởi gân.
// Chia tia nước lớn thành nhiều tia nhỏ → tiêu tán động năng nhanh hơn nhiều.
inlet_rib_t  = 1.2;    // bề dày gân giữa 2 cửa sổ (3 perimeter × nozzle 0.4)
inlet_gap_w  = 3.5;    // ⚠️ LỆCH tài liệu (2.5): 2.5 chỉ dư 0.5mm so hạt 2mm, NGAY
                       // CỬA VÀO. Hạt nghẽn ở đây = không vào khay = không đếm được
                       // (hỏng chính phép đo, tệ hơn kẹt ở cửa ra). 3.5 = 1.75× hạt.
inlet_n_gap  = 4;      // số cửa sổ
inlet_pitch  = inlet_gap_w + inlet_rib_t;                              // = 4.7
inlet_span   = inlet_n_gap * inlet_gap_w + (inlet_n_gap - 1) * inlet_rib_t;  // = 17.6

// (c) VÁCH CONG tiêu năng — chắn đường đi thẳng cổng vào → cổng ra (short-circuiting)
baffle_t     = 1.2;    // bề dày vách (3 perimeter FDM)
baffle_r_mid = 16.4;   // ⚠️ LỆCH tài liệu (17.6): 17.6 → hành lang chỉ 1.8mm < hạt
                       // 2mm ⇒ hạt KHÔNG lọt, kẹt trong túi cổng vào (lối thoát duy
                       // nhất) ⇒ vi phạm ràng buộc cứng "mọi hạt ra hết".
                       // GIÁ PHẢI TRẢ: vùng ảnh hóa Ø40 → Ø31.6. Chỉnh tham số này
                       // sau khi in thử nếu muốn đổi cân bằng.
baffle_h     = 7.0;    // ⚠️ LỆCH tài liệu (5.0): 5.0 < mực nước 6 ⇒ ~50% lưu lượng
                       // tràn qua NÓC vách, xả động năng thẳng vào MẶT NƯỚC (chỗ cần
                       // phẳng nhất). Lý do "thoát bọt" của tài liệu không áp dụng vì
                       // vách là HÀNG RÀO HỞ 2 ĐẦU, bọt thoát tự do quanh 2 đầu mút.
baffle_angle = 90;     // góc quét cung (độ), tâm tại −X (đối diện cổng vào)
                       // Bo 2 đầu mút: bán nguyệt r = baffle_t/2 = 0.6 — ⚠️ tài liệu
                       // ghi fillet_r=2.0 là BẤT KHẢ THI trên vách dày 1.2mm.
baffle_corridor = tray_inner/2 - (baffle_r_mid + baffle_t/2);  // DẪN XUẤT = 3.0

// GỜ NỐI (rib) nối vách cong vào thành khay — sửa lỗi Critical: vách cong KHÔNG
// chạm gì (đáy khay hở, đối diện bellmouth) → 2 khối rời (CGAL Volumes=3), sẽ in
// thành mảnh nhựa RỜI rơi vào lòng khay rồi trôi ra kẹt cổng Ø6. 3 gờ nối vách↔
// thành, đặt Ở TRÊN MẶT NƯỚC (z: water_depth → baffle_h — vách cao hơn nước đúng
// để chừa khoảng này) nên hạt (luôn ngập nước, di chuyển ở z<water_depth) không
// bao giờ chạm gờ; hành lang baffle_corridor 3.0mm dưới mực nước vẫn thông suốt
// 100% theo chiều sâu ngập z=0..water_depth. TUYỆT ĐỐI không hạ z dưới xuống
// dưới water_depth — làm vậy là tái tạo đúng lỗi Critical đã sửa ở đây.
baffle_rib_n      = 3;              // số gờ nối
baffle_rib_w      = 3.0;            // bề rộng tiếp tuyến mỗi gờ (đủ khỏe, ≥ nozzle×~7)
baffle_rib_angles = [150, 180, 210]; // góc đặt gờ (độ) — trong khoảng quét vách 135°–225°
// Đáy gờ TÁCH RIÊNG khỏi water_depth (không viết thẳng water_depth trong module)
// để assert bên dưới có ý nghĩa thật: nếu sau này ai "dọn gọn" hạ đáy gờ xuống
// (vd đổi thành water_depth − 1) thì assert bắt được ngay khi render, thay vì
// một assert luôn-đúng không bao giờ fail.
baffle_rib_z_bot  = water_depth;    // đáy gờ (mm) — PHẢI ≥ water_depth, xem assert

// (Bellmouth) MIỆNG LOE cổng RA — chống dồn ứ + dội sóng ngược tại miệng lỗ xả
// Nhô VÀO lòng khay (KHÔNG khoét lõm vào thành): thành chỉ dày 2mm, khoét lõm bo
// R=3 sẽ ăn hết thịt quanh ngạnh OD8 (còn ~0.25mm) → vỡ khi in/dùng.
bell_fillet_r = 3.0;   // bán kính bo loe (r/d = 0.5 ≫ ngưỡng 0.15 ⇒ K: 0.5 → <0.05)
bell_wall     = 1.2;   // bề dày vỏ loa kèn (3 perimeter)
bell_steps    = 24;    // số đoạn xấp xỉ cung 90° khi revolve
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

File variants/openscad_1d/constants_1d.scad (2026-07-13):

// ============================================================================
// constants_1d.scad — Biến thể Đầu dò quang 1D (Optofluidic Sensor Head)
// ----------------------------------------------------------------------------
// TOÀN BỘ hằng số + assert. Nguồn: variants/02_openscad_plan_1d.md.
// KHÔNG liên quan baseline openscad/constants.scad (hệ tách rời).
//
// HỆ TRỤC:
//   O = ĐIỂM CẢM BIẾN (chùm laser ∩ trục ống). Z = trục dòng chảy (nước chảy −Z).
//   X = trục chùm: laser ở −X, PD hấp thụ ở +X. Y = tán xạ: PD tán xạ ở +Y (90°).
//   Cả 3 phần tử quang nằm ở mặt phẳng z=0 = MẶT TÁCH clamshell.
// ============================================================================

$fn = 48;

// ---------------------------------------------------------------- In / dung sai
tol   = 0.2;   // khe trượt FDM
wall  = 3.0;   // thành tối thiểu quanh lỗ (kín sáng + cứng)

// ---------------------------------------------------------------- Ống kênh (MUA SẴN — không in)
tube_od   = 10.0;   // ống trong bán sẵn
tube_id   = 8.0;    // hạt 5mm lọt (biên 3mm)
tube_clr  = 0.3;    // khe bore ôm ống
tube_len  = 60.0;   // thò 2 đầu nối ống bơm
part_max  = 5.0;    // hạt lớn nhất (kiểm nghẽn)
tube_bore_d = tube_od + tube_clr;         // = 10.3
tube_bore_r = tube_bore_d / 2;            // = 5.15

// ---------------------------------------------------------------- Khối gá (clamshell tách z=0)
block_w  = 50.0;    // X — chứa barrel laser + PD 2 bên
block_d  = 44.0;    // Y — chứa PD tán xạ +Y
block_h  = 36.0;    // Z — 2 nửa mỗi 18
split_z  = 0.0;     // mặt tách = mặt phẳng quang

// ---------------------------------------------------------------- Laser (MUA SẴN)
laser_dia = 6.0;    // barrel
laser_len = 20.0;   // đoạn thân trong rãnh
laser_ap  = 2.5;    // khẩu độ ra sát ống (giới hạn sáng)
ap_len    = 3.0;    // chiều dài kênh khẩu độ (vai chặn barrel/PD)
laser_shoulder_x = tube_bore_r + ap_len;  // = 8.15: vai chặn barrel

// ---------------------------------------------------------------- Photodiode ×2 (MUA SẴN — BPW34/Ø5)
pd_dia = 5.0;       // gói Ø5
pd_len = 8.0;       // thân PD trong rãnh
pd_ap  = 3.0;       // khẩu độ PD nhìn O
scatter_ang = 90;   // góc PD tán xạ (chỉ ghi chú; hình học đặt ở +Y)
pd_shoulder = tube_bore_r + ap_len;       // = 8.15

// ---------------------------------------------------------------- Vít M3 (kẹp 2 nửa)
m3_clear   = 3.4;   // lỗ thông nửa TRÊN
m3_tap     = 2.8;   // lỗ tự-ren nửa DƯỚI
screw_inset = 5.0;  // vít cách mép
cbore_d    = 6.0;   // khoét đầu vít M3 chìm (mặt trên nửa TRÊN)
cbore_h    = 3.0;   // sâu khoét đầu vít

// ---------------------------------------------------------------- Đăng ký 2 nửa (chốt định vị) + giữ ống
// Chốt Ø3 RỜI (que thép 3mm / in rời) cắm vào lỗ ở CẢ 2 nửa → canh khít mặt tách,
// khử xê dịch 0.4mm do khe vít, tránh lệch nửa-rãnh quang. (Bản _001 thiếu — lỗi khớp.)
dowel_d      = 3.0;
dowel_hole_d = 3.3;                 // lỗ chốt (khe cắm)
dowel_depth  = 4.0;                 // sâu lỗ mỗi nửa
dowel_pos    = [[16, -11], [-16, -11]]; // 2 chốt ở nửa −Y (tránh rãnh tán xạ +Y & rãnh X)
tube_set_d   = 2.5;   // lỗ tự-ren vít GIỮ ỐNG (chống tuột), từ mặt −Y, nửa TRÊN
tube_set_z   = 8.0;   // cao độ vít giữ ống (trên mặt quang z=0, nằm trong nửa trên)

// ---------------------------------------------------------------- Màu (mượn palette baseline)
col_block    = [0.20, 0.20, 0.22];       // nhựa in ĐEN NHÁM (thân quang)
col_acrylic  = [0.65, 0.88, 0.95, 0.30]; // ống trong
col_water    = [0.35, 0.65, 0.90, 0.30]; // nước
col_metal    = [0.78, 0.78, 0.80];       // barrel laser
col_laser    = [0.95, 0.15, 0.15];       // tia/đầu laser đỏ
col_pd       = [0.10, 0.20, 0.35];       // gói PD
col_pd_win   = [0.30, 0.75, 0.65];       // cửa sổ PD (teal)
col_part     = [0.15, 0.15, 0.14];       // hạt mẫu

// ============================================================================
// HELPER
// ============================================================================

// 4 lỗ vít M3 ở 4 góc (thẳng đứng). Dùng: m3_corners() cylinder(...);
module m3_corners() {
    for (sx = [-1, 1]) for (sy = [-1, 1])
        translate([sx*(block_w/2 - screw_inset), sy*(block_d/2 - screw_inset), 0])
            children();
}

// 2 vị trí chốt định vị. Dùng: dowel_positions() cylinder(...);
module dowel_positions() {
    for (p = dowel_pos) translate([p[0], p[1], 0]) children();
}

// Trụ nằm theo trục X từ x0 → x1 (x1 > x0)
module x_cyl(d, x0, x1) {
    translate([x0, 0, 0]) rotate([0, 90, 0]) cylinder(d = d, h = x1 - x0);
}
// Trụ nằm theo trục Y từ y0 → y1 (y1 > y0)
module y_cyl(d, y0, y1) {
    translate([0, y0, 0]) rotate([-90, 0, 0]) cylinder(d = d, h = y1 - y0);
}

// ============================================================================
// ASSERT lắp ghép
// ============================================================================
assert(tube_id - part_max >= 2, "hạt lớn nhất phải còn biên ≥2mm trong ống (chống nghẽn)");
assert(laser_ap < laser_dia, "khẩu độ laser phải nhỏ hơn barrel (có vai chặn)");
assert(pd_ap  < pd_dia,      "khẩu độ PD phải nhỏ hơn gói PD (có vai chặn)");
assert(laser_shoulder_x < block_w/2, "rãnh laser phải nằm trong nửa khối");
assert(pd_shoulder < block_w/2, "rãnh PD hấp thụ (+X) phải nằm trong nửa khối");
assert(pd_shoulder < block_d/2, "rãnh PD tán xạ (+Y) phải nằm trong nửa khối");
assert(sqrt(pow(block_w/2 - screw_inset, 2) + pow(block_d/2 - screw_inset, 2))
       - m3_clear/2 > tube_bore_r + wall, "lỗ vít 4 góc phải cách bore ống ≥ wall");
assert(block_h/2 - laser_dia/2 >= wall, "thành trên/dưới rãnh quang ≥ wall");
assert(scatter_ang >= 30 && scatter_ang <= 150,
       "góc tán xạ giữ trong [30,150]° để rãnh không đè trục chùm X & mặt −Y (chốt/vít giữ ống)");
assert(tube_set_z + tube_set_d/2 < block_h/2, "vít giữ ống phải nằm gọn trong nửa TRÊN");
assert(cbore_h < block_h/2 - wall, "khoét đầu vít không được mỏng nóc nửa trên");

echo(str("== 1D sensor constants OK == tube OD/ID = ", tube_od, "/", tube_id,
         " | block WxDxH = ", block_w, "x", block_d, "x", block_h,
         " | shoulder x = ", laser_shoulder_x));

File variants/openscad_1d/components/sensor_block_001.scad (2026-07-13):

// ============================================================================
// sensor_block_001.scad — Khối gá quang clamshell (2 nửa tách ở z=0).
// Rãnh quang nằm ở mặt tách → in úp mặt tách xuống, KHÔNG cần support.
// ============================================================================
include <../constants_1d.scad>

// Các hốc quang (trừ khỏi khối đặc) — KHÔNG gồm lỗ vít (xử lý theo nửa).
module _optical_cavities() {
    // Bore ống dọc Z
    cylinder(d = tube_bore_d, h = block_h + 2, center = true);
    // Laser (−X): rãnh barrel + khẩu độ tới ống
    x_cyl(laser_dia, -(block_w/2 + 1), -laser_shoulder_x);
    x_cyl(laser_ap,  -laser_shoulder_x, -tube_bore_r + 0.1);
    // PD hấp thụ (+X): khẩu độ + rãnh
    x_cyl(pd_ap,  tube_bore_r - 0.1, pd_shoulder);
    x_cyl(pd_dia, pd_shoulder, block_w/2 + 1);
    // PD tán xạ (+Y): khẩu độ + rãnh
    y_cyl(pd_ap,  tube_bore_r - 0.1, pd_shoulder);
    y_cyl(pd_dia, pd_shoulder, block_d/2 + 1);
}

// Khối đặc trước khi khoét.
module _block_solid() {
    cube([block_w, block_d, block_h], center = true);
}

// which = "upper" (z>0) hoặc "lower" (z<0).
module sensor_block_half(which = "lower") {
    zmin = (which == "upper") ? 0 : -block_h;
    screw_d = (which == "upper") ? m3_clear : m3_tap;
    color(col_block)
    difference() {
        intersection() {
            _block_solid();
            translate([-block_w, -block_d, zmin]) cube([2*block_w, 2*block_d, block_h]);
        }
        _optical_cavities();
        m3_corners() cylinder(d = screw_d, h = block_h + 2, center = true);
    }
}

// Cả 2 nửa tại chỗ (xem lắp ghép).
module sensor_block_assembled() {
    sensor_block_half("upper");
    sensor_block_half("lower");
}

// Preview mặc định: 2 nửa tách nhau kiểm mặt cắt rãnh.
sensor_block_half("lower");
translate([0, 0, 24]) sensor_block_half("upper");

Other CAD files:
openscad/print/black/print_window_retainer.stl
openscad/print/black/print_slot_plugs.stl
openscad/print/print_top_lid_xiao.stl
variants/openscad_1d/components/sensor_block_002.scad
base/Assembly_Matchboxscope_injectionmolded_IM_Matchboxscope_base_old_1.stl
openscad/aqua_scope_assembly_001.scad
openscad/components/accessories_001.scad
openscad/components/esp32cam_001.scad
openscad/components/flow_tray_001.scad
openscad/components/flow_tray_002.scad
openscad/components/flow_tray_003.scad
openscad/components/glass_window_top_001.scad
openscad/components/led_module_001.scad
openscad/components/light_box_001.scad
openscad/components/light_box_002.scad
openscad/components/pump_station_001.scad
openscad/components/pump_station_002.scad
openscad/components/top_cap_001.scad
openscad/components/top_cap_002.scad
openscad/components/top_cap_003.scad
openscad/components/top_cap_004.scad
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

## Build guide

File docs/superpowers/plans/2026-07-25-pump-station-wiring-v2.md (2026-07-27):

# Trạm bơm v2 — giấu dây & gọn hóa đấu nối Implementation Plan

> **For agentic workers:** REQUIRED SUB-SKILL: Use superpowers:subagent-driven-development (recommended) or superpowers:executing-plans to implement this plan task-by-task. Steps use checkbox (`- [ ]`) syntax for tracking.

**Goal:** Sửa cụm in 3D "trạm bơm gọn" (`pump_station_001` → `pump_station_002`) để khắc phục 3 vấn đề dây điện phát hiện khi lắp thật: (1) jack DC 12V lộ ngoài không chỗ giấu, (2) dây động cơ phải vòng qua thân bơm do 2 chân dẹt lệch ~180°, (3) dây logic ra ESP32 không có strain-relief.

**Architecture:** Giữ nguyên kiến trúc v1 đã duyệt (đế liền + hộp hở nắp L298N + 2 yên kẹp bơm kiểu lồng-từ-trên). Tạo file component mới `pump_station_002.scad` (kế thừa toàn bộ code từ `_001`, KHÔNG sửa `_001` tại chỗ — theo quy ước versioning của repo), áp 3 thay đổi hình học cục bộ, rồi trỏ lại các file `print_*.scad` và `aqua_scope_assembly_001.scad` sang bản `_002`.

**Tech Stack:** OpenSCAD (`.scad`), scripts versioning/preview/export tại `.claude/skills/{openscad,preview-scad,export-stl}/scripts/`.

## Global Constraints

- Vật liệu in: PETG (khe lồng yên kẹp cần đàn hồi nhẹ) — không đổi.
- KHÔNG sửa `pump_station_001.scad` tại chỗ — mọi thay đổi vào file mới `pump_station_002.scad` (quy ước "phiên bản mới nhất thắng" của repo, giống `top_cap_002` supersede `_001`).
- KHÔNG đổi driver bơm (giữ L298N) hay firmware (`firmware/pump_l298n_xiao/pump_l298n_xiao.ino` không đổi).
- KHÔNG thiết kế đế/khung chung nối trạm bơm với khối quang chính — 2 cụm vẫn đặt rời trên bàn.
- KHÔNG thiết kế ngàm giữ đầu jumper phía dây động cơ (OUT1/OUT2) — user sẽ HÀN trực tiếp, phía dây logic (IN1/IN2/EN/GND) vẫn giữ jumper đực-cái.
- Mọi hằng số kích thước chưa đo từ phần cứng thật phải có comment "CHƯA ĐO ... — xác nhận khi lắp" (quy ước xuyên suốt `constants.scad`).
- Không có framework test tự động cho OpenSCAD trong repo này — chu trình kiểm chứng là: render PNG bằng `render-scad.sh` rồi **đọc ảnh bằng Read tool** để xác nhận hình học đúng như mô tả (thay cho unit test).
- Nguồn duy nhất cho phạm vi thay đổi: [docs/superpowers/specs/2026-07-25-pump-station-wiring-v2-design.md](../specs/2026-07-25-pump-station-wiring-v2-design.md) — không thêm tính năng ngoài spec này.

---

## File Structure

| File | Vai trò |
|---|---|
| `openscad/constants.scad` | Thêm 1 block hằng số mới (v2) cạnh block `pump_station_*` hiện có (dòng ~163-218) — KHÔNG sửa hằng số cũ. |
| `openscad/components/pump_station_002.scad` | **File mới.** Copy nguyên `pump_station_001.scad`, áp 3 thay đổi: lỗ panel-mount jack DC (thay khe input), rãnh dẫn dây trên yên kẹp gần hộp + nới khe output, gờ bo tròn khe logic. |
| `openscad/print/print_pump_station.scad` | Sửa 1 dòng `use` trỏ sang `_002`. |
| `openscad/print/print_pump_station_lid.scad` | Sửa 1 dòng `use` trỏ sang `_002` (module `pump_station_lid()` không đổi nội dung). |
| `openscad/aqua_scope_assembly_001.scad` | Sửa 1 dòng `use` (dòng 31) trỏ sang `_002`. |
| `openscad/print/print_pump_station.stl`, `print_pump_station_lid.stl` | Xuất lại sau khi đổi component. |
| `openscad/components/pump_station_002.png` | Ảnh preview mới (theo đúng quy ước đã có với `pump_station_001.png`). |

---

### Task 1: Thêm hằng số v2 vào `constants.scad`

**Files:**
- Modify: `openscad/constants.scad:218` (chèn block mới ngay sau dòng `pump_station_wid = ...`, trước block "BIẾN THỂ ESP32-CAM" ở dòng 220)

**Interfaces:**
- Produces: các hằng số sau, dùng bởi Task 2–4 trong `pump_station_002.scad`:
  `dc_jack_hole_d`, `dc_jack_hole_z`, `dc_jack_shelf_h`, `dc_jack_shelf_w`, `dc_jack_shelf_depth`, `wire_notch_w_out`, `pump_wire_groove_w`, `pump_wire_groove_d`, `logic_notch_fillet_r`.

- [ ] **Step 1: Chèn block hằng số mới**

Mở `openscad/constants.scad`, tìm dòng:
```
pump_station_wid = max(l298n_box_od_w, pump_clamp_od) + 2*pump_station_margin; // = 60
```
(dòng 218), chèn NGAY SAU dòng này (trước dòng trống + comment "BIẾN THỂ ESP32-CAM"):

```openscad

// ---------------------------------------------------------------- Trạm bơm v2: giấu dây & gọn hóa đấu nối (2026-07-25)
// Nguồn: docs/superpowers/specs/2026-07-25-pump-station-wiring-v2-design.md
// Rút kinh nghiệm lắp thật bản in v1: (1) jack DC 12V rời lộ ngoài không chỗ giấu,
// (2) dây động cơ phải vòng qua thân bơm do 2 chân dẹt lệch ~180° quanh chu vi,
// (3) dây logic ra ESP32 không có strain-relief. CHƯA ĐO các kích thước dưới đây.
dc_jack_hole_d       = 9.5;   // Ø lỗ panel-mount jack DC 5.5×2.1mm — CHƯA ĐO module thật
dc_jack_hole_z       = l298n_foot_h + 10.0; // tâm lỗ tính từ mặt đế — ước lượng ngang tầm cầu đấu vít
dc_jack_shelf_h      = 3.0;   // cao gờ đỡ board jack+cầu đấu, tính từ mặt đế
dc_jack_shelf_w      = 24.0;  // rộng gờ đỡ (dọc Y) — CHƯA ĐO board thật (~20×15mm điển hình)
dc_jack_shelf_depth  = 15.0;  // sâu gờ đỡ (dọc X, từ mặt trong thành −X vào) — CHƯA ĐO

wire_notch_w_out     = 7.0;   // bề rộng khe dây OUTPUT (+X, ra yên kẹp) — rộng hơn wire_notch_w
                              // vì chứa 2 dây hàn trực tiếp + co nhiệt song song

pump_wire_groove_w   = 3.0;   // rộng rãnh dẫn dây trên mặt −X yên kẹp gần hộp L298N
pump_wire_groove_d   = 1.5;   // sâu rãnh dẫn dây (khoét vào mặt ngoài khối, KHÔNG xuyên lòng máng)

logic_notch_fillet_r = 2.0;   // bán kính gờ bo tròn thoát dây logic (strain relief), cạnh +Y
```

- [ ] **Step 2: Kiểm tra cú pháp — render lại 1 file hiện có (chưa dùng hằng số mới) để xác nhận `constants.scad` không lỗi cú pháp**

Run:
```bash
bash .claude/skills/preview-scad/scripts/render-scad.sh openscad/print/print_pump_station.scad --output "$SCRATCHPAD/task1_syntax_check.png"
```
(thay `$SCRATCHPAD` bằng đường dẫn scratchpad thật của phiên làm việc)

Expected: `Success: Preview saved to ...` — không có dòng `ERROR`/`Parser error` nào từ OpenSCAD. File này vẫn dùng `pump_station_001.scad` (chưa đổi), nên đây chỉ là phép thử "constants.scad thêm block mới không phá vỡ include hiện có".

- [ ] **Step 3: Commit**

```bash
git add openscad/constants.scad
git commit -m "feat(openscad): thêm hằng số v2 cho trạm bơm - giấu jack DC, dẫn dây, strain relief"
```

---

### Task 2: Tạo `pump_station_002.scad` + thay đổi 1 (lỗ panel-mount jack DC 12V)

**Files:**
- Create: `openscad/components/pump_station_002.scad`

**Interfaces:**
- Consumes: hằng số từ Task 1 (`dc_jack_hole_d`, `dc_jack_hole_z`, `dc_jack_shelf_h`, `dc_jack_shelf_w`, `dc_jack_shelf_depth`) + toàn bộ hằng số `pump_station_001.scad` đã dùng (`l298n_*`, `pump_clamp_*`, `pump_station_*`) — không đổi.
- Produces: module `pump_station()`, `pump_station_lid()` — **cùng tên và cùng chữ ký (không tham số) như `_001`**, để Task 5 chỉ cần đổi dòng `use`, không đổi lời gọi.

- [ ] **Step 1: Xác nhận số phiên bản kế tiếp**

Run:
```bash
cd openscad/components && bash ../../.claude/skills/openscad/scripts/version-scad.sh pump_station && cd ../..
```
Expected output chứa dòng: `Next version: pump_station_002`

- [ ] **Step 2: Tạo file `pump_station_002.scad` — copy `_001` nguyên vẹn + đổi khe input thành lỗ jack DC**

Tạo `openscad/components/pump_station_002.scad` với nội dung sau (toàn bộ file, đã copy từ `_001` và áp thay đổi 1; thay đổi 2 và 3 sẽ chèn ở Task 3, 4):

```openscad
// ============================================================================
// pump_station_002.scad — Trạm bơm gọn v2: giấu dây & gọn hóa đấu nối
// ----------------------------------------------------------------------------
// Kế thừa pump_station_001.scad (đế liền + hộp che L298N hở nắp + 2 yên kẹp RS365).
// Nguồn thay đổi: docs/superpowers/specs/2026-07-25-pump-station-wiring-v2-design.md
// (rút kinh nghiệm lắp thật bản in v1, xem ảnh user cung cấp trong buổi brainstorm).
//
// 3 thay đổi so _001 (KHÔNG đổi kiến trúc tổng thể — đế/hộp hở nắp/yên kẹp lồng
// từ trên giữ nguyên như đã duyệt ở spec v1):
//   1. Khe dây INPUT 12V (cạnh −X hộp L298N) → LỖ TRÒN panel-mount cho jack DC
//      5.5×2.1mm + gờ đỡ board nhỏ (jack + cầu đấu vít) bên trong.
//   2. Khe dây OUTPUT động cơ (cạnh +X) nới rộng (dây hàn trực tiếp, bỏ đầu jumper)
//      + thêm rãnh dẫn dây trên mặt ngoài yên kẹp GẦN hộp (bù 2 chân dẹt mô-tơ
//      lệch ~180° quanh chu vi, không cùng hướng khe lồng đỉnh khối).
//   3. Khe dây LOGIC (cạnh +Y, ra ESP32) thêm gờ bo tròn (strain relief) ở mép khe.
//
// Trục dài đế = X. Hộp L298N ở đầu −X (gần), 2 yên kẹp ở đầu +X (xa) — không đổi
// so _001. Tâm lỗ khoan yên kẹp nằm ngang dọc trục X, khớp hướng trục bơm.
// ============================================================================
include <../constants.scad>

EPS = 0.05;

// ---------------------------------------------------------------- Hộp L298N (hở nắp — đáy = mặt đế bên dưới)
module l298n_box_walls() {
    difference() {
        cube([l298n_box_od_l, l298n_box_od_w, l298n_box_h]);
        // Khoét lòng hộp (chừa 4 thành; không chừa sàn — sàn = mặt đế)
        translate([l298n_box_wall, l298n_box_wall, -EPS])
            cube([l298n_box_id_l, l298n_box_id_w, l298n_box_h + 2*EPS]);
        // v2: LỖ PANEL-MOUNT jack DC 12V — cạnh −X (thay khe dây input trần cũ của
        // _001). Xuyên thẳng qua thành, tâm cao dc_jack_hole_z tính từ mặt đế —
        // CHƯA ĐO module jack thật, xác nhận khi lắp (xem constants.scad).
        translate([-EPS, l298n_box_od_w/2, dc_jack_hole_z])
            rotate([0, 90, 0])
                cylinder(d = dc_jack_hole_d, h = l298n_box_wall + 2*EPS, $fn = 32);
        // Khe dây OUTPUT động cơ — cạnh +X (hướng về phía yên kẹp bơm). v2: nới rộng
        // (wire_notch_w_out thay wire_notch_w) vì 2 dây HÀN trực tiếp + co nhiệt cần
        // chỗ hơn dây trần đơn — đầu jumper phía này đã bỏ (user sẽ hàn).
        translate([l298n_box_od_l - l298n_box_wall - EPS, l298n_box_od_w/2 - wire_notch_w_out/2,
                   l298n_box_h - wire_notch_h])
            cube([l298n_box_wall + 2*EPS, wire_notch_w_out, wire_notch_h + EPS]);
        // Khe dây LOGIC (IN1/IN2/EN + GND lên ESP32) — cạnh +Y (về khối quang chính).
        // Vị trí/bề rộng giữ nguyên như _001 (vẫn dùng jumper đực-cái, không đổi).
        translate([l298n_box_od_l/2 - wire_notch_w/2, l298n_box_od_w - l298n_box_wall - EPS,
                   l298n_box_h - wire_notch_h])
            cube([wire_notch_w, l298n_box_wall + 2*EPS, wire_notch_h + EPS]);
        // Khe thoát khí — cạnh −Y (đối diện khe dây logic, phía tản nhiệt board)
        for (i = [0 : l298n_vent_n - 1])
            translate([l298n_box_wall + 4 + i * (l298n_box_id_l - 8) / (l298n_vent_n - 1) - l298n_vent_w/2,
                       -EPS, 6])
                cube([l298n_vent_w, l298n_box_wall + 2*EPS, l298n_box_h - 6 - wire_notch_h - 2]);
    }
    // 4 gờ đỡ góc board (board tựa lên — KHÔNG cần khớp lỗ vít board thật)
    foot_sz = 5.0;
    for (cx = [l298n_box_wall + 1, l298n_box_od_l - l298n_box_wall - 1 - foot_sz])
        for (cy = [l298n_box_wall + 1, l298n_box_od_w - l298n_box_wall - 1 - foot_sz])
            translate([cx, cy, 0])
                cube([foot_sz, foot_sz, l298n_foot_h]);
    // 2 gờ vít M3 tự-ren giữ nắp, 2 góc chéo
    boss_d = 6.0;
    for (p = [[l298n_box_wall + boss_d/2 + 1, l298n_box_wall + boss_d/2 + 1],
              [l298n_box_od_l - l298n_box_wall - boss_d/2 - 1,
               l298n_box_od_w - l298n_box_wall - boss_d/2 - 1]])
        translate([p[0], p[1], 0])
            difference() {
                cylinder(d = boss_d, h = l298n_box_h - 3, $fn = 32);
                translate([0, 0, 5])
                    cylinder(d = l298n_lid_screw_d, h = l298n_box_h - 3 - 5 + EPS, $fn = 24);
            }
    // v2: gờ đỡ (shelf) cho board nhỏ jack DC + cầu đấu vít — tựa ngang tầm lỗ jack,
    // sát mặt trong thành −X. Kích thước board thật CHƯA ĐO (ước lượng ~20×15mm) —
    // xác nhận footprint không đội board L298N chính khi lắp thật (2 board cùng
    // đáy hộp, chỉ khác chiều cao gờ đỡ).
    translate([l298n_box_wall, l298n_box_od_w/2 - dc_jack_shelf_w/2, 0])
        cube([dc_jack_shelf_depth, dc_jack_shelf_w, dc_jack_shelf_h]);
    // v2: gờ bo tròn thoát dây logic (strain relief) — cạnh +Y, ngoài khe dây logic.
    // Tâm đặt đúng mặt ngoài thành (y = l298n_box_od_w) để nửa trong chồng khít vào
    // thành (union liền khối), nửa ngoài nhô ra làm mặt cong cho dây tựa khi bẻ góc.
    translate([l298n_box_od_l/2, l298n_box_od_w, l298n_box_h - wire_notch_h])
        rotate([0, 90, 0])
            cylinder(d = 2*logic_notch_fillet_r, h = wire_notch_w, center = true, $fn = 32);
}

// Nắp hộp L298N — chi tiết in RIÊNG (print_pump_station_lid.scad) — KHÔNG đổi so _001
module pump_station_lid() {
    boss_d = 6.0;
    difference() {
        cube([l298n_box_od_l, l298n_box_od_w, l298n_lid_t]);
        for (p = [[l298n_box_wall + boss_d/2 + 1, l298n_box_wall + boss_d/2 + 1],
                  [l298n_box_od_l - l298n_box_wall - boss_d/2 - 1,
                   l298n_box_od_w - l298n_box_wall - boss_d/2 - 1]])
            translate([p[0], p[1], -EPS])
                cylinder(d = l298n_lid_clr_d, h = l298n_lid_t + 2*EPS, $fn = 24);
    }
}

// ---------------------------------------------------------------- Yên kẹp bơm: khối + lỗ khoan ngang + khe lồng từ trên
// v2: tham số wire_groove — khi true, khoét thêm rãnh dẫn dây trên mặt −X (hướng
// hộp L298N) để bù trường hợp 2 chân dẹt mô-tơ không cùng hướng khe lồng đỉnh khối.
// Chỉ bật true ở yên kẹp GẦN hộp L298N (xem pump_station()).
module pump_clamp_post(wire_groove = false) {
    block_h  = pump_clamp_od;
    center_z = pump_clamp_od / 2;
    difference() {
        translate([0, -pump_clamp_od/2, 0])
            cube([pump_clamp_w, pump_clamp_od, block_h]);
        // Lỗ khoan ngang (trục X = trục bơm) giữ thân trụ động cơ
        translate([-EPS, 0, center_z])
            rotate([0, 90, 0])
                cylinder(d = pump_clamp_id, h = pump_clamp_w + 2*EPS, $fn = 64);
        // Khe lồng từ ĐỈNH khối xuống tâm lỗ (hẹp hơn Ø lỗ — PETG dẻo ép giữ bơm)
        translate([-EPS, -pump_clamp_slot_w/2, center_z])
            cube([pump_clamp_w + 2*EPS, pump_clamp_slot_w, block_h - center_z + EPS]);
        // Rãnh zip-tie trên đỉnh khối, cắt ngang qua khe lồng (bù sai số Ø bơm thật)
        translate([pump_clamp_w/2 - pump_clamp_strap_w/2, -pump_clamp_od/2 - EPS, block_h - 1.5])
            cube([pump_clamp_strap_w, pump_clamp_od + 2*EPS, 1.5 + EPS]);
        // v2: rãnh dẫn dây động cơ trên mặt NGOÀI khối (mặt −X, hướng hộp L298N),
        // chạy dọc trục Z từ đáy khối tới tầm lỗ khoan — dẫn dây từ rãnh đế lên tới
        // chỗ chân dẹt mô-tơ, PHÒNG trường hợp chân dẹt không lộ ra đúng khe lồng
        // đỉnh khối. CHƯA ĐO góc lệch thật giữa 2 chân dẹt — xem giả định #3 trong
        // spec v2. Không xuyên vào lòng máng (chỉ khoét mặt ngoài).
        if (wire_groove)
            translate([-EPS, -pump_wire_groove_w/2, -EPS])
                cube([pump_wire_groove_d + EPS, pump_wire_groove_w, center_z + EPS]);
    }
}

// ---------------------------------------------------------------- Rãnh dây nối hộp L298N ↔ yên kẹp bơm (khoét vào mặt đế) — KHÔNG đổi so _001
module wire_channel(length) {
    ch_w = 6.0; ch_d = 1.5;
    translate([0, -ch_w/2, -ch_d])
        cube([length, ch_w, ch_d + EPS]);
}

// ---------------------------------------------------------------- Trạm bơm hoàn chỉnh (đế + hộp L298N không nắp + 2 yên kẹp)
module pump_station() {
    box_x    = pump_station_margin;
    clamp_x0 = box_x + l298n_box_od_l + pump_station_gap;
    clamp_x1 = clamp_x0 + pump_clamp_gap;
    base_y   = pump_station_wid / 2;
    chan_len = clamp_x0 - (box_x + l298n_box_od_l);

    // Đế (khoét rãnh dây trên mặt)
    difference() {
        translate([0, -base_y, -pump_station_base_t])
            cube([pump_station_len, pump_station_wid, pump_station_base_t]);
        translate([box_x + l298n_box_od_l, 0, 0])
            wire_channel(chan_len);
    }
    // 4 chân đế góc
    foot_sz = 6.0;
    for (fx = [3, pump_station_len - 3 - foot_sz])
        for (fy = [-base_y + 3, base_y - 3 - foot_sz])
            translate([fx, fy, -pump_station_base_t - pump_station_foot_h])
                cube([foot_sz, foot_sz, pump_station_foot_h]);
    // Hộp L298N (căn giữa theo bề rộng đế)
    translate([box_x, -l298n_box_od_w/2, 0]) l298n_box_walls();
    // 2 yên kẹp bơm — yên GẦN hộp (clamp_x0) bật wire_groove=true để dẫn dây từ
    // rãnh đế lên tới chân dẹt mô-tơ (v2); yên xa (clamp_x1) giữ nguyên.
    translate([clamp_x0, 0, 0]) pump_clamp_post(wire_groove = true);
    translate([clamp_x1, 0, 0]) pump_clamp_post();
}

// Xem lẻ
pump_station();
translate([0, 80, 0]) pump_station_lid();
```

- [ ] **Step 3: Render preview**

Run:
```bash
bash .claude/skills/preview-scad/scripts/render-scad.sh openscad/components/pump_station_002.scad --output "$SCRATCHPAD/task2_check.png" --size 1200x900
```
Expected: `Success: Preview saved to ...`, không có lỗi OpenSCAD.

- [ ] **Step 4: Đọc ảnh để xác nhận hình học**

Dùng Read tool mở `$SCRATCHPAD/task2_check.png`. Kỳ vọng thấy:
- Hộp L298N vẫn có 4 gờ góc + 2 trụ vít chéo bên trong (không đổi so _001).
- Cạnh hộp GẦN yên kẹp (phía −X, xa yên kẹp — hướng "ra ngoài trạm") có **1 lỗ tròn xuyên thành** thay vì khe chữ nhật trần như bản _001 cũ.
- Không còn khe chữ nhật ở vị trí input cũ.

Nếu lỗ tròn không xuất hiện hoặc vị trí sai (ví dụ xuyên nhầm cạnh), sửa lại `translate`/`rotate` ở Step 2 rồi lặp lại Step 3–4.

- [ ] **Step 5: Commit**

```bash
git add openscad/components/pump_station_002.scad
git commit -m "feat(openscad): pump_station_002 - lỗ panel-mount jack DC 12V thay khe dây input"
```

---

### Task 3: Thay đổi 2 — nới khe output + rãnh dẫn dây yên kẹp gần hộp

**Files:**
- Modify: `openscad/components/pump_station_002.scad` (đã tạo ở Task 2)

**Interfaces:**
- Consumes: `wire_notch_w_out`, `pump_wire_groove_w`, `pump_wire_groove_d` (Task 1).
- Note: thay đổi này **đã được viết sẵn trong nội dung Task 2 Step 2** ở trên (khe output dùng `wire_notch_w_out`, module `pump_clamp_post(wire_groove=false)` có nhánh `if (wire_groove)`, và lời gọi `pump_clamp_post(wire_groove = true)` cho yên gần hộp). Task này chỉ là bước **kiểm chứng độc lập** hình học của riêng 2 thay đổi đó bằng cách render cận cảnh — không cần sửa code thêm trừ khi Step 1 phát hiện sai lệch.

- [ ] **Step 1: Render cận cảnh cụm yên kẹp + cạnh output hộp**

Run (dùng `--camera` để phóng vào vùng yên kẹp gần hộp; toạ độ ước lượng theo layout `pump_station_len=128`, hộp ở x≈0-52, yên gần ở x≈72-80):
```bash
bash .claude/skills/preview-scad/scripts/render-scad.sh openscad/components/pump_station_002.scad --output "$SCRATCHPAD/task3_check.png" --size 1200x900 --camera 40,0,20,60,0,0,150
```

- [ ] **Step 2: Đọc ảnh để xác nhận**

Dùng Read tool mở `$SCRATCHPAD/task3_check.png`. Kỳ vọng thấy:
- Khe dây ở cạnh hộp hướng về yên kẹp (+X) **rộng hơn rõ rệt** so với khe logic đối diện (bên kia hộp) — vì `wire_notch_w_out=7.0` > `wire_notch_w=6.0`.
- Yên kẹp GẦN hộp (yên đầu tiên theo hướng +X) có **1 rãnh dọc trên mặt hướng về hộp** (mặt −X của khối yên), chạy từ đáy khối lên khoảng nửa chiều cao khối (tới tâm lỗ khoan).
- Yên kẹp XA hộp (yên thứ hai) **KHÔNG** có rãnh này — chỉ có khối kẹp + khe lồng + rãnh zip-tie như bản gốc.

Nếu rãnh không xuất hiện đúng vị trí (ví dụ lộn qua yên xa, hoặc xuyên vào lòng máng thay vì chỉ ở mặt ngoài), sửa lại `translate` trong nhánh `if (wire_groove)` của `pump_clamp_post()` (Task 2 Step 2) rồi lặp lại Step 1–2.

- [ ] **Step 3: Commit (chỉ commit nếu Step 2 phát hiện cần sửa code; nếu hình học đã đúng từ Task 2, bỏ qua bước này)**

```bash
git add openscad/components/pump_station_002.scad
git commit -m "fix(openscad): điều chỉnh rãnh dẫn dây yên kẹp / khe output sau kiểm tra render"
```

---

### Task 4: Thay đổi 3 — xác nhận gờ bo tròn thoát dây logic

**Files:**
- Modify: `openscad/components/pump_station_002.scad` (đã tạo ở Task 2; gờ bo tròn đã viết sẵn ở Task 2 Step 2 trong `l298n_box_walls()`)

**Interfaces:**
- Consumes: `logic_notch_fillet_r` (Task 1).
- Note: cũng giống Task 3 — code đã có sẵn từ Task 2, task này là bước kiểm chứng render độc lập cho riêng chi tiết này.

- [ ] **Step 1: Render cận cảnh cạnh logic (+Y) của hộp**

Run:
```bash
bash .claude/skills/preview-scad/scripts/render-scad.sh openscad/components/pump_station_002.scad --output "$SCRATCHPAD/task4_check.png" --size 1200x900 --camera 26,52,27,26,26,10,120
```

- [ ] **Step 2: Đọc ảnh để xác nhận**

Dùng Read tool mở `$SCRATCHPAD/task4_check.png`. Kỳ vọng thấy: ở mép ngoài khe dây logic (cạnh +Y, gần đỉnh hộp), có **1 gờ cong lồi ra** (nửa trụ tròn nhô khỏi mặt thành phẳng) thay vì mép vuông 90° sắc cạnh như bản _001. Gờ này nằm đúng bề rộng khe (không tràn ra ngoài khe logic).

Nếu gờ bị chìm vào trong thành (không nhô ra ngoài) hoặc lệch vị trí khỏi khe, sửa lại toạ độ `translate` của khối `cylinder` bo tròn trong `l298n_box_walls()` (Task 2 Step 2) rồi lặp lại Step 1–2.

- [ ] **Step 3: Commit (chỉ nếu có sửa)**

```bash
git add openscad/components/pump_station_002.scad
git commit -m "fix(openscad): điều chỉnh gờ bo tròn thoát dây logic sau kiểm tra render"
```

---

### Task 5: Trỏ các file in + assembly tổng sang `pump_station_002`

**Files:**
- Modify: `openscad/print/print_pump_station.scad:7`
- Modify: `openscad/print/print_pump_station_lid.scad:5`
- Modify: `openscad/aqua_scope_assembly_001.scad:31`

**Interfaces:**
- Consumes: `pump_station()`, `pump_station_lid()` từ `pump_station_002.scad` (Task 2–4) — chữ ký không đổi so `_001` nên không cần sửa lời gọi, chỉ đổi dòng `use`.

- [ ] **Step 1: Sửa `print_pump_station.scad`**

Trong `openscad/print/print_pump_station.scad`, đổi dòng 7:
```openscad
use <../components/pump_station_001.scad>
```
thành:
```openscad
use <../components/pump_station_002.scad>
```

- [ ] **Step 2: Sửa `print_pump_station_lid.scad`**

Trong `openscad/print/print_pump_station_lid.scad`, đổi dòng 5:
```openscad
use <../components/pump_station_001.scad>
```
thành:
```openscad
use <../components/pump_station_002.scad>
```

- [ ] **Step 3: Sửa `aqua_scope_assembly_001.scad`**

Trong `openscad/aqua_scope_assembly_001.scad`, đổi dòng 31:
```openscad
use <components/pump_station_001.scad>
```
thành:
```openscad
use <components/pump_station_002.scad>
```

- [ ] **Step 4: Render lại 2 file in + assembly tổng để xác nhận không lỗi**

Run:
```bash
bash .claude/skills/preview-scad/scripts/render-scad.sh openscad/print/print_pump_station.scad --output "$SCRATCHPAD/task5_print.png"
bash .claude/skills/preview-scad/scripts/render-scad.sh openscad/print/print_pump_station_lid.scad --output "$SCRATCHPAD/task5_lid.png"
bash .claude/skills/preview-scad/scripts/render-scad.sh openscad/aqua_scope_assembly_001.scad --output "$SCRATCHPAD/task5_assembly.png" --size 1400x1000
```

Expected: cả 3 lệnh in ra `Success: Preview saved to ...`, không có `ERROR`/assert fail nào từ `aqua_scope_assembly_001.scad` (file này có các `assert()` kiểm tra kích thước tổng thể — nếu `pump_station_002` phá vỡ giả định về `pump_station_len`/`pump_station_wid`, assembly sẽ báo lỗi ở bước này).

- [ ] **Step 5: Đọc ảnh `task5_assembly.png` để xác nhận trạm bơm vẫn xuất hiện đúng vị trí**

Dùng Read tool mở `$SCRATCHPAD/task5_assembly.png`. Kỳ vọng: cụm trạm bơm (đế + hộp + yên kẹp) vẫn nằm cạnh mô hình `pump_rs365()` placeholder ở vùng +X như trước (không dịch chuyển vị trí, không biến mất, không lỗi hình học vỡ vụn).

- [ ] **Step 6: Commit**

```bash
git add openscad/print/print_pump_station.scad openscad/print/print_pump_station_lid.scad openscad/aqua_scope_assembly_001.scad
git commit -m "feat(openscad): trỏ print_pump_station + assembly sang pump_station_002"
```

---

### Task 6: Xuất STL, kiểm tra manifold, cập nhật ảnh preview component

**Files:**
- Modify (regenerate): `openscad/print/print_pump_station.stl`
- Modify (regenerate): `openscad/print/print_pump_station_lid.stl`
- Create: `openscad/components/pump_station_002.png`

**Interfaces:**
- Consumes: `print_pump_station.scad`, `print_pump_station_lid.scad` (đã trỏ sang `_002` ở Task 5).

- [ ] **Step 1: Xuất STL cho đế + hộp + yên kẹp**

Run:
```bash
bash .claude/skills/export-stl/scripts/export-stl.sh openscad/print/print_pump_station.scad --output openscad/print/print_pump_station.stl
```
Expected: không có cảnh báo `non-manifold`, `self-intersect`, hay `degenerate` trong output. Nếu có, quay lại Task 2–4 sửa hình học (thường do 2 solid chạm nhau đúng 1 mặt phẳng với `EPS` không đủ) rồi lặp lại.

- [ ] **Step 2: Xuất STL cho nắp hộp L298N**

Run:
```bash
bash .claude/skills/export-stl/scripts/export-stl.sh openscad/print/print_pump_station_lid.scad --output openscad/print/print_pump_station_lid.stl
```
Expected: không có cảnh báo manifold/self-intersect/degenerate (nắp không đổi so `_001` nên đây chủ yếu là phép thử "vẫn xuất được sau khi đổi include").

- [ ] **Step 3: Tạo ảnh preview component mới (theo đúng quy ước đã có `pump_station_001.png`)**

Run:
```bash
bash .claude/skills/preview-scad/scripts/render-scad.sh openscad/components/pump_station_002.scad --output openscad/components/pump_station_002.png --size 1200x900
```

- [ ] **Step 4: Đọc ảnh `pump_station_002.png` lần cuối — xác nhận cả 3 thay đổi cùng hiện diện**

Dùng Read tool mở `openscad/components/pump_station_002.png`. Kỳ vọng thấy đồng thời:
1. Lỗ tròn panel-mount ở cạnh hộp xa yên kẹp (thay khe input cũ).
2. Khe output (cạnh hộp gần yên kẹp) rộng hơn khe logic đối diện + rãnh dọc trên mặt yên kẹp gần hộp.
3. Gờ bo tròn ở khe logic (cạnh hộp còn lại, hướng ra ngoài — phía ESP32).

- [ ] **Step 5: Commit**

```bash
git add openscad/print/print_pump_station.stl openscad/print/print_pump_station_lid.stl openscad/components/pump_station_002.png
git commit -m "build(openscad): xuất STL + preview pump_station_002 (giấu jack DC, dẫn dây, strain relief)"
```

---

## Giả định chưa xác nhận (kế thừa từ spec, không chặn triển khai)

1. Đường kính lỗ panel-mount jack DC thật (9.5mm chỉ là điển hình cho jack 5.5×2.1mm) — đo lại khi lắp, sửa `dc_jack_hole_d` trong `constants.scad` nếu lệch.
2. Kích thước + vị trí board nhỏ (jack + cầu đấu) thật — hiện ước lượng ~20×15mm, `dc_jack_shelf_h`/`dc_jack_shelf_w`/`dc_jack_shelf_depth`/`dc_jack_hole_z` có thể cần chỉnh lại để board thật vừa khít và không đội board L298N chính (2 board cùng đáy hộp).
3. Góc lệch thật giữa 2 chân dẹt trên thân mô-tơ RS365 (giả định ~180° dựa theo ảnh) — nếu góc lệch thật khác, có thể cần xoay vị trí rãnh dẫn dây (`pump_wire_groove_*`) trong `pump_clamp_post()`.
4. Các giả định cũ từ spec v1 (kích thước board L298N 43×43×27mm, Ø thân bơm 31.5mm) vẫn CHƯA ĐO, không đổi trong plan này.

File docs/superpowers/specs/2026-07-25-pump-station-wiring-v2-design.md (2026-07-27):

# Thiết kế: Trạm bơm v2 — giấu dây & gọn hóa đấu nối (sau khi lắp thật)

**Ngày:** 2026-07-25
**Trạng thái:** Đã duyệt bởi user, chờ viết plan triển khai.
**Kế thừa:** [2026-07-24-pump-station-mount-design.md](2026-07-24-pump-station-mount-design.md)
(đã in `openscad/print/print_pump_station.stl` + `print_pump_station_lid.stl`, đã lắp thử
thật với module L298N + dây jumper đực-cái).

## Bối cảnh

Sau khi lắp thật bản in `pump_station_001` (xem ảnh user cung cấp), phát sinh 3 vấn đề
mà thiết kế v1 chưa lường tới:

1. **Ngõ vào 12V lộ ra ngoài, không chỗ giấu.** User dùng 1 module nhỏ rời gồm jack DC
   barrel + cầu đấu vít 2 chân (nối vào chân input 12V của L298N), hiện nằm lỏng lẻo bên
   ngoài hộp — thiết kế v1 chỉ có khe dây trần xuyên thành, không tính tới module này.
2. **Dây ra động cơ bơm phải vòng qua thân bơm.** 2 chân dẹt (spade) trên thân trụ mô-tơ
   RS365 nằm cách nhau ~180° quanh chu vi (không cùng hướng về phía hộp L298N) — 1 dây
   (vàng/lam trong ảnh) nối thẳng vào hộp, còn dây kia (cam) phải vòng lỏng lẻo qua dưới
   thân bơm mới tới được chân còn lại. Thiết kế v1 chỉ có 1 rãnh dây thẳng nối hộp↔yên kẹp,
   không tính đường vòng này.
3. **Dây tín hiệu ESP32→L298N (IN1/IN2/EN/GND) chạy lộ thiên, mất thẩm mỹ.** Trạm bơm và
   khối quang chính (ống + XIAO ESP32-S3) hiện là **2 cụm rời, đặt tự do trên bàn, không
   chung đế/khung** — dây tín hiệu nối 2 cụm hiện không có strain-relief hay đường dẫn nào.

User xác nhận (qua hỏi-đáp trước khi viết spec này):
- **Vẫn dùng jumper đực-cái cho phần logic** (IN1/IN2/EN/GND lên ESP32) — không hàn.
- **Dây ra động cơ bơm (OUT1/OUT2) sẽ HÀN trực tiếp** vào chân spade, bỏ đầu jumper —
  nên không cần thiết kế ngàm giữ đầu jumper ở phía này, chỉ cần khe hở đủ cho dây trần +
  co nhiệt.
- **Jack 12V: khoét lỗ xuyên vỏ hộp, gắn cố định kiểu panel-mount** — không chỉ là 1 khoang
  chứa module rời.
- **2 cụm (trạm bơm / khối quang) không có đế chung** — vẫn đặt rời trên bàn, nên KHÔNG
  thiết kế rãnh dây cứng nối liền 2 cụm (không khả thi vì chúng di chuyển độc lập).

## Mục tiêu

Sửa `pump_station_001` (đế + hộp L298N + yên kẹp bơm) → `pump_station_002`, chỉ thay đổi
3 điểm dây điện nêu trên, **giữ nguyên kiến trúc tổng thể** (đế liền, hộp hở nắp, yên kẹp
kiểu lồng-từ-trên) đã duyệt ở bản v1.

## Kiến trúc — 3 thay đổi

### 1. Lỗ panel-mount cho jack DC 12V (thay khe dây input cũ)

- Thay khe dây bán-nguyệt input 12V (cạnh −X hộp L298N) bằng **1 lỗ tròn xuyên thành**,
  đường kính `dc_jack_hole_d` (mặc định 9.5mm — cỡ phổ biến cho jack DC 5.5×2.1mm dạng
  module nhỏ có ren, **CHƯA ĐO module thật của user — xác nhận khi lắp**).
- Tâm lỗ đặt ở giữa bề rộng thành, cao ngang tầm cầu đấu vít trên board L298N (để dây
  input ra khỏi jack đi thẳng vào board, không phải vòng).
- Bên trong, thêm 1 **gờ đỡ (shelf)** cao `dc_jack_shelf_h` sát mặt trong thành, để board
  nhỏ (jack + cầu đấu) tựa lên và ép sát ra lỗ — cố định bằng ma sát + keo nến (module này
  không có lỗ bắt vít chuẩn). Không thiết kế ngàm khớp chính xác kích thước board (vì chưa
  đo) — chỉ cần gờ đỡ phẳng đủ rộng.
- Nắp hộp (`pump_station_lid`) không đổi, vẫn đậy phía trên; module jack nằm thấp hơn mép
  hộp nên không đội nắp.

### 2. Rãnh dẫn dây vòng quanh yên kẹp bơm (thay vì dây vòng tự do)

- Khe dây output (cạnh +X hộp, hướng về yên kẹp) **nới rộng nhẹ** từ `wire_notch_w=6.0` lên
  đủ chứa 2 dây trần + co nhiệt song song (ước lượng `wire_notch_w=7.0`, không cần rộng bằng
  đầu jumper cũ vì đã bỏ đầu nối nhựa ở phía này).
- Thêm **rãnh dẫn dây (wire guide groove)** khoét nông trên mặt ngoài khối yên kẹp
  (`pump_clamp_post`), chạy dọc theo 1 phần chu vi lòng máng (song song với lỗ khoan ngang,
  ở mặt ngoài khối chứ không xuyên vào lòng máng) — đủ sâu (~1.5mm) và rộng (~3mm) để ép
  1 dây trần + co nhiệt vào, giữ nó áp sát thân bơm thay vì lơ lửng. Rãnh này chạy từ vị trí
  gần hộp L298N vòng ra phía sau khối yên kẹp gần nhất với hộp — đủ dùng cho trường hợp
  người dùng xoay bơm sao cho 2 chân dẹt nằm gần mặt phẳng chứa rãnh nhất có thể (khuyến
  nghị lắp: xoay bơm khi lồng vào yên sao cho 2 chân dẹt cùng nằm về phía mặt có rãnh,
  giảm tối đa đoạn dây phải treo tự do ở đoạn cuối).
- Không đảm bảo rãnh khớp chính xác 100% mọi góc xoay chân dẹt thật (vì chưa đo vị trí góc
  thật trên bơm) — đây là cải thiện thẩm mỹ + strain relief một phần, không phải khớp kỹ
  thuật tuyệt đối. Ghi chú "CHƯA ĐO góc lệch thật giữa 2 chân dẹt" trong code.

### 3. Gờ thoát dây bo cong (strain relief) cho dây logic ra ESP32

- Khe dây logic hiện tại (cạnh +Y hộp, hướng khối quang chính) giữ nguyên vị trí, nhưng
  thêm 1 **gờ lồi bo tròn (radius) ở mép ngoài khe**, để dây bẻ cong mượt khi ra khỏi hộp
  thay vì gập khúc 90° sát cạnh vỏ (giảm mỏi dây + gọn mắt hơn).
- **Không** thiết kế rãnh/kênh cứng nối 2 cụm (trạm bơm ↔ khối quang) — vì 2 cụm đặt rời,
  di chuyển độc lập, rãnh cứng sẽ vô nghĩa. Khuyến nghị dùng ống lò xo quấn dây (spiral
  wrap) mua ngoài cho đoạn dây tự do này — nằm ngoài phạm vi bản in.

## File / constants cần thêm

- Sửa `openscad/components/pump_station_001.scad` → tạo mới
  `openscad/components/pump_station_002.scad` (dùng script version-scad.sh, supersede
  `_001` giống cách `top_cap_002` supersede `_001` trước đây). Thay đổi trong
  `l298n_box_walls()` (lỗ jack thay khe input), `pump_clamp_post()` (thêm rãnh dẫn dây),
  và khe dây logic (thêm gờ bo tròn).
- Sửa `openscad/print/print_pump_station.scad` trỏ sang `pump_station_002.scad`.
- `openscad/print/print_pump_station_lid.scad` — không đổi logic, chỉ cần trỏ include nếu
  module `pump_station_lid()` được giữ trong file `_002` mới (copy nguyên, không sửa).
- Sửa `openscad/constants.scad`, thêm cạnh block `l298n_*`/`pump_clamp_*` hiện có (~dòng
  163-218):
  - `dc_jack_hole_d = 9.5;` — kèm comment "CHƯA ĐO module jack thật — xác nhận khi lắp".
  - `dc_jack_shelf_h = 3.0;` — cao gờ đỡ board jack tính từ đáy hộp.
  - `dc_jack_shelf_depth = 15.0;` — sâu gờ đỡ (đủ tựa board nhỏ ~20×15mm điển hình, CHƯA ĐO).
  - Thêm hằng riêng `wire_notch_w_out = 7.0` chỉ dùng cho khe dây output (cạnh +X, ra yên
    kẹp bơm). Giữ nguyên `wire_notch_w = 6.0` cho khe logic (+Y) — khe input cũ (−X) bị
    THAY THẾ hoàn toàn bởi lỗ jack (`dc_jack_hole_d`) nên không còn dùng `wire_notch_w` ở
    cạnh đó nữa.
  - `pump_wire_groove_w = 3.0;` `pump_wire_groove_d = 1.5;` — rãnh dẫn dây trên yên kẹp.
  - `logic_notch_fillet_r = 2.0;` — bo tròn gờ thoát dây logic.
- Sửa `openscad/aqua_scope_assembly_001.scad`: đổi `use <components/pump_station_001.scad>`
  → `use <components/pump_station_002.scad>` tại khối `if (show_pump)`.

## Không làm trong thiết kế này

- Không đổi driver bơm hay firmware (giữ nguyên L298N + `pump_l298n_xiao.ino`).
- Không thiết kế ngàm giữ đầu jumper phía dây động cơ (user sẽ hàn trực tiếp).
- Không thiết kế đế/khung chung nối trạm bơm với khối quang chính (2 cụm vẫn rời).
- Không làm kín nước hoàn toàn (giữ nguyên định hướng "che bụi/dây gọn", không phải hộp
  IP-rated) — vẫn đúng như spec v1.
- Không đảm bảo khớp chính xác 100% vị trí góc thật của 2 chân dẹt trên mô-tơ (chưa đo).

## Giả định cần xác nhận sau (không chặn triển khai, gắn cờ trong code)

1. Đường kính lỗ panel-mount jack DC thật (9.5mm chỉ là điển hình cho jack 5.5×2.1mm).
2. Kích thước board nhỏ (jack + cầu đấu) thật để gờ đỡ vừa khít hơn (hiện ước lượng
   ~20×15mm, CHƯA ĐO).
3. Góc lệch thật giữa 2 chân dẹt trên thân mô-tơ RS365 (giả định ~180°, dựa theo ảnh —
   CHƯA ĐO chính xác bằng thước đo góc).
4. Các giả định cũ từ spec v1 (kích thước board L298N 43×43×27mm, Ø thân bơm 31.5mm) vẫn
   CHƯA ĐO, không đổi trong bản v2 này.

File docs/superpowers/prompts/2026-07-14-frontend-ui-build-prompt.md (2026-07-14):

# Prompt: build Frontend UI (Module 5) — Aqua Scope QC Dashboard

> Copy toàn bộ khối dưới đây, dán vào một session Claude Code mới **mở tại thư mục repo này**.
> Prompt đã tự chứa hợp đồng dữ liệu quan trọng, nhưng vẫn yêu cầu Claude đọc SPEC gốc trước khi code.

---

Bạn đang làm việc trong repo Aqua Scope. Nhiệm vụ: **code Module 5 — toàn bộ Frontend** cho traceability dashboard, đúng theo thiết kế đã chốt. Backend Module 1–3 (ingest + read API) đã xong; **không sửa backend**, chỉ thêm tầng trình bày.

## Việc cần đọc trước khi gõ dòng code đầu tiên
1. `docs/superpowers/specs/2026-07-14-web-system-design.md` — **nguồn sự thật**. Đọc kỹ **§7 (Frontend design)** + §5 (data contract) + §12 (Boundaries) + §13 (Success criteria).
2. `CLAUDE.md` §Application context, §Operating cycle — bối cảnh QC nước đầu vào, yêu cầu traceability.
3. `web/backend/app/routers/samples.py` và `models.py` — để dùng **đúng tên field** API trả về (đừng đoán).

## Ngôn ngữ & người dùng
- **Toàn bộ UI tiếng Việt.** Người dùng: nhân viên QC nhà máy thực phẩm (LAN, desktop) + hội đồng chấm đồ án (trình chiếu). Phong cách: **hiện đại, thoáng, ấn tượng khi demo**, sentence case (không ALL CAPS).

## Ràng buộc kiến trúc (bất biến — vi phạm là sai)
- Jinja2 server-rendered + **vanilla JS** + **Chart.js v4 vendor LOCAL**. **KHÔNG build step** (không React/webpack/npm), **KHÔNG CDN** (`<script src="http...">` là cấm — chạy LAN offline).
- **Append-only ở tầng UI:** tuyệt đối **không** có nút/ form sửa/xoá mẫu ở bất kỳ trang nào.
- Trang `/stream` là **mock thuần frontend**: KHÔNG gọi endpoint backend mới, **KHÔNG ghi DB**.
- Không thêm dependency Python mới, không đổi DB schema, không đổi data contract §5. Nếu thấy cần — **hỏi trước**.

## Hợp đồng dữ liệu API (khớp code backend hiện tại)
- `GET /api/samples?page=&page_size=&batch_lot=&from=&to=` → `{items:[SampleSummary], total, page, page_size}`.
  - `SampleSummary`: `id, sample_code, batch_lot?, device_id, captured_at, received_at, particle_count, image_path`.
- `GET /api/samples/{id}` → `SampleDetail`: các field summary + `image_width?, image_height?, px_per_mm?, raw_metadata_json, particles[], size_histogram{bin_width_mm,max_mm,bins:[{start,end,count}]}, label_distribution{label:count}`.
  - `ParticleOut`: `blob_index, centroid_x, centroid_y, bbox_x, bbox_y, bbox_w, bbox_h, area_px, size_mm, label, confidence`.
- `GET /api/export.csv?...` (cùng filter) → tải CSV audit.
- Ảnh serve read-only tại `/images/...` (giá trị `image_path` đã là đường dẫn tương đối, vd `images/S....jpg`).
- **Datetime** trả về là **naive-UTC** (DATA-1). Frontend phải **đổi sang giờ địa phương** khi hiển thị.

## Design tokens (định nghĩa 1 chỗ trong `static/css/style.css` = CSS custom properties, mirror sang JS)
- **Palette thương hiệu:** Teal `#1D9E75`/`#0F6E56` (chủ đạo, = trạng thái "Đạt") · Amber `#EF9F27`/`#854F0B` (cảnh báo, gợi đèn nền backlit) · Blue `#378ADD` (dòng chảy/thông tin) · Xám `#888780` (trung tính).
- **Bảng màu nhãn hạt DUY NHẤT** — dùng nhất quán ở bbox overlay + chart + chip bảng (người xem học 1 lần):
  `plastic`=teal `#1D9E75` · `bubble`=blue `#378ADD` · `organic`=amber `#EF9F27` · `fiber`=xám `#888780` · `unknown`=xám nhạt `#B4B2A9`. Nhãn lạ ngoài danh sách → màu `unknown`. (Class list chốt: plastic, bubble, organic, fiber.)
- Nền sáng sạch; card trắng bo 12px viền 0.5px; metric tile nền `--surface-1` bo 8px không viền; 2 cấp đậm (400/500); khoảng trắng rộng.
- **Dark mode + WCAG AA bắt buộc:** mọi màu qua CSS custom properties có biến thể sáng/tối; chữ trên nền màu dùng stop đậm cùng gam; focus ring rõ; `aria-label` cho nút chỉ-icon; canvas bbox có mô tả text thay thế; điều hướng bàn phím được.
- **Chip trạng thái QC:** "Đạt" (teal) / "Cảnh báo" (amber). Ngưỡng là hằng số `WARN_PARTICLE_COUNT` trong `config.py` (**default: cảnh báo khi `particle_count > 0`** — có hạt là cảnh báo). Không hard-code ngưỡng trong template.

## Bốn trang phải build (chi tiết ở SPEC §7.2)
1. **`/` Dashboard** — lưới module cân bằng:
   - Header: logo + "Aqua Scope — bảng điều khiển QC" + chip "LAN · demo" + nút "Xuất CSV".
   - Hàng 4 metric tiles (`auto-fit`): Mẫu hôm nay · Tổng hạt hôm nay · Tỉ lệ nhựa · Cảnh báo (thẻ cảnh báo nền amber nhạt khi >0).
   - Hàng 2 cột `minmax(0,1.5fr)+minmax(0,1fr)`: card **"Mẫu mới nhất"** (ảnh backlit thu nhỏ + bbox overlay + chip trạng thái + bảng meta + link "Xem chi tiết") | card **"Phân bố loại"** (donut theo bảng màu nhãn + chú giải %).
   - Card **"5 mẫu gần nhất"**: bảng mini + link nổi bật "Xem tất cả (lịch sử / audit)".
2. **`/history` Audit** — bảng phân trang (`mã mẫu·lô·thời gian·số hạt·chip loại·trạng thái·[chi tiết]`); **thanh filter dạng form GET** (khoảng ngày, mã lô) → server render lại (không client-side state); nút "Xuất CSV" mang đúng filter hiện tại; dense rows (viền ngang mảnh, không bọc card từng dòng); **không nút sửa/xoá**.
3. **`/samples/{id}` Chi tiết** — 2 cột: trái = ảnh JPEG + `<canvas>` overlay bbox (sticky khi cuộn, màu theo `label`, hover blob → tô đậm + tooltip label/size_mm/confidence); phải = bảng từng hạt (label·confidence·size_mm·area_px·centroid) + **histogram kích thước** (Chart.js, bin từ `size_histogram`) + **chart phân bố loại** (từ `label_distribution`) + khối `<details>` "raw metadata JSON" hiển thị `raw_metadata_json` nguyên văn.
4. **`/stream` Stream (demo)** — canvas + vanilla JS mô phỏng dòng chảy backlit: trường xám sáng, hạt trôi xuống, mỗi hạt bbox màu theo loại + nhãn (dùng đúng bảng màu §1.2 + `PX_PER_MM=14` để "cùng một hệ" với ảnh tĩnh). Nút "Bật stream" (play/pause) + toggle "Hiện detection" (cú reveal khi demo). HUD live: số hạt đang thấy · chip phân bố loại · fps · thanh chỉnh tốc độ. **Banner trung thực bắt buộc:** "Chế độ demo — mô phỏng, không ghi vào lịch sử."

## Component & trạng thái (phần plan cũ còn thiếu — phải làm)
- **Empty state** mỗi trang (Dashboard/History/Detail-404): minh hoạ nhẹ + 1 câu mời hành động, vd "Chưa có mẫu nào. Chạy `mock_sender.py` để nạp dữ liệu demo." — không để bảng trơ.
- **`bbox_overlay.js`**: tự tính hệ số scale từ kích thước hiển thị thực của `<img>` so với `image_width/height` gốc → overlay khớp dù ảnh co giãn responsive. Dùng lại cho cả trang Chi tiết và card Dashboard.
- **`charts.js`**: Chart.js vendor local `static/js/vendor/chart.umd.min.js`; màu lấy từ bảng nhãn thống nhất.
- **Loading/lỗi:** ảnh chưa tải → skeleton; API lỗi → dòng thông báo ngắn, không first-person, không lộ exception (vd "Không tải được dữ liệu. Thử lại").
- **Responsive:** desktop 2 cột → **≤820px gập 1 cột**; bảng cuộn ngang **trong khung riêng** (`overflow-x:auto`), body trang **không** cuộn ngang; đơn vị tương đối (`rem`, `%`, `minmax(0,1fr)`), ảnh `max-width:100%`.

## Cây file cần tạo (Module 5, không phát sinh file backend mới)
```
web/backend/app/
├── routers/pages.py            # GET /, /history, /samples/{id}, /stream (Jinja2 TemplateResponse)
├── templates/ base.html · index.html · history.html · sample_detail.html · stream.html
└── static/
    ├── css/style.css           # design tokens (custom properties, dark mode)
    └── js/ vendor/chart.umd.min.js · bbox_overlay.js · charts.js · stream_sim.js
```
Wiring Module 6: `main.py` include router `pages.py`; nav trong `base.html` có 3 mục (Dashboard · Lịch sử · Stream demo). Thêm `WARN_PARTICLE_COUNT` vào `config.py`.

## Phong cách code
Theo đúng exemplar các file backend hiện có: module docstring nêu "tại sao" + trỏ mục spec; type hint đầy đủ; comment giải thích quyết định (không comment điều hiển nhiên); helper `_snake_case`. Xem SPEC §10.

## Định nghĩa "xong" (kiểm chứng được — SPEC §13)
- 3 trang đọc + `/stream` render đúng dữ liệu mock; overlay bbox khớp ảnh (kể cả khi resize); donut/histogram đúng số liệu.
- **Không** có `<script src="http...">` bất kỳ đâu; Chart.js chạy từ vendor local.
- Không có đường sửa/xoá; `/stream` không gọi backend, có banner trung thực.
- Dark mode hoạt động; bàn phím điều hướng được; tương phản đạt AA.
- Có smoke test render 3 trang với fixture + test `/stream` không gọi backend (SPEC §11).

## Cách làm việc
Đề xuất chạy qua skill `superpowers:writing-plans` (hoặc `agent-skills:plan`) để phân rã Module 5 thành các bước nhỏ verify được, rồi build tuần tự. Trước khi build, xác nhận với tôi: giá trị default `WARN_PARTICLE_COUNT` và có cần mock data sẵn (chạy `mock_sender.py`) để xem UI không.

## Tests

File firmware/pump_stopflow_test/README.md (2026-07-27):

# Pump Stop-Flow Test — Firmware

> **Công cụ test bơm độc lập** — không phải firmware của trạm. Firmware chính
> thức là [`firmware/aqua_scope_station/`](../aqua_scope_station/).

Firmware **test độc lập**, chỉ để kiểm tra relay + bơm RS365 12V chạy đúng chu
trình **Stop-Flow** trước khi ráp vào khay thật. Không đụng tới camera/CV.

## Phần cứng

- Board: **ESP32-CAM (AI-Thinker)** hoặc bất kỳ board ESP32 nào có GPIO13 rảnh.
  **Cấp nguồn riêng cho ESP32** (5V qua USB/FTDI) — không rút 5V từ nguồn 12V bơm.
- Module relay 1 kênh, opto-cách ly, **active-LOW** (theo BOM đã chốt trong dự án).
- Bơm màng **RS365 12V** + adapter **12V/2A**.
- Tụ gốm **0.1µF** hàn ngang 2 cực bơm (chống nhiễu chổi than — bắt buộc).

## Đấu nối

| Relay | Nối tới |
|---|---|
| IN | **GPIO13** |
| VCC | 5V (ESP32-CAM) |
| GND | GND chung (ESP32 **+** nguồn 12V bơm) |
| COM | 12V+ (adapter) |
| NO | Bơm (+) |

Bơm (−) → GND 12V. **GND phải chung** giữa ESP32 và nguồn 12V.

> **Vì sao GPIO13?** Trên AI-Thinker, GPIO13 không trùng chân camera (xem
> `camera_pins.h` trong `firmware/Esp32 cam/CameraWebServer/`). Nó chỉ trùng
> SD card 4-bit (`HS2_DATA3`) — không dùng khe SD trong bài test này thì dùng
> thoải mái.

> **An toàn active-LOW:** relay đóng (bơm chạy) khi GPIO ở mức LOW. Firmware
> kéo chân lên HIGH (tắt) **ngay dòng đầu tiên của `setup()`**, trước khi làm
> gì khác, để bơm không tự chạy lúc boot/nạp code.

## Cài đặt & nạp

1. Arduino IDE + gói board **esp32 by Espressif**.
2. Board: **AI Thinker ESP32-CAM** (hoặc board ESP32 tương ứng).
3. Mở `pump_stopflow_test.ino`, chọn đúng Port, **Upload**.

## Chu trình mặc định (chỉnh được qua Serial, không cần nạp lại)

```
FILLING (bơm ON, 5s) → SETTLING (bơm OFF, 2s) → FLUSHING (bơm ON mạnh, 5s)
→ COOLDOWN (bơm OFF, 3s) → lặp lại
```

Mở **Serial Monitor 115200 baud** để xem log chuyển pha và gõ lệnh:

| Lệnh | Ý nghĩa |
|---|---|
| `p` | in trạng thái hiện tại |
| `0` / `1` | tạm dừng auto, ép bơm tắt/bật (test tay) |
| `a` | chạy lại auto Stop-Flow |
| `f3000` / `s1500` / `x8000` / `c5000` | chỉnh thời gian fill/settle/flush/cooldown (ms) |
| `r` | khôi phục timing mặc định |
| `?` | in lại menu |

## Sau khi test xong

Nếu relay/bơm chạy đúng nhịp, bước tiếp theo là gộp state machine này vào
`aqua_scope_cam.ino` (thêm điều khiển đèn nền + gọi chụp ảnh ở pha `SETTLING`,
đúng theo chu trình Stop-Flow trong `README.md`/`CLAUDE.md` gốc của dự án).

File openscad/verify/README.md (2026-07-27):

# Kiểm & mô phỏng khay Macro-Flow trước khi in

3 công cụ ở đây trả lời 3 câu hỏi khác nhau. `export-stl.sh` (đã có sẵn) chỉ trả
lời câu 0 — không phải là "mô phỏng hoạt động", chỉ là "in được không":

| # | Câu hỏi | Công cụ | Bắt được lỗi loại gì |
|---|---|---|---|
| 0 | STL có in được không (mesh kín, không tự cắt nhau)? | `export-stl.sh` (đã có sẵn) | Lỗ mesh, tam giác suy biến |
| 1 | Hạt 2mm có ĐI QUA được từ cửa vào tới cổng ra không? | `flow_path_probe_001.scad` | Tắc nghẽn hình học (đã từng: miệng loe bị bịt kín) |
| 2 | Có mảnh nào rời khỏi khối chính / thành nào mỏng bất thường không? | `verify_flow_tray.py` | Mảnh trôi nổi (đã từng: vách baffle rời khối), thành mỏng dưới ngưỡng in |
| 3 | Sóng có thực sự dập trong 2s không? Cổng ra có thực sự chống xoáy không? | SimScale (CFD) — xem PHẦN B dưới | Động lực học dòng chảy thật — KHÔNG kiểm được bằng OpenSCAD |

Cả 3 công cụ 0-2 đều là kiểm **hình học tĩnh** — chúng chỉ xác nhận "đường có
thông, thành có đủ dày, không có mảnh rời". Không cái nào mô phỏng NƯỚC THẬT
chảy — muốn biết sóng có dập trong 2 giây hay cổng ra có xoáy hút khí hay
không, bắt buộc phải sang CFD (PHẦN B) hoặc in thử + đổ nước thật.

## PHẦN A — 3 công cụ kiểm hình học (chạy được ngay, không cần tài khoản/cài gì)

### A1. Dò đường nước bằng probe — `flow_path_probe_001.scad`

Dựng 1 chuỗi capsule đường kính = `particle_max` (2mm, đúng bằng hạt lớn nhất
cần đo) đi theo tuyến hẹp nhất đã chốt trong thiết kế (cửa vào → hành lang
3.0mm ngoài vách cong → vùng mở giữa khay → miệng loe → lòng cổng ra). Đổi
`MODE` trong file:

```bash
# MODE = "overlay" → xem trực quan (probe đỏ trong suốt đè lên khay bán trong suốt)
bash .claude/skills/preview-scad/scripts/render-scad.sh openscad/verify/flow_path_probe_001.scad --size 1400x1000 --camera 0,0,3,55,0,25,150 --output openscad/verify/flow_path_probe_001_overlay.png

# MODE = "check" → kiểm số: intersection(flow_tray(), probe) phải RỖNG
bash .claude/skills/export-stl/scripts/export-stl.sh openscad/verify/flow_path_probe_001.scad --output openscad/verify/flow_path_check.stl
# Log kết thúc bằng "Current top level object is empty." = THÔNG (đạt).
# Nếu export ra file STL thật có hình học = TẮC — mở STL đó xem đúng vị trí bị chặn.
```

**Kết quả hiện tại (2026-07-25, `flow_tray_003.scad`): THÔNG — đã xác nhận.**

Khi đổi `baffle_r_mid`/`baffle_angle`/`inlet_gap_w`/bellmouth trong
`constants.scad`, chạy lại đúng 2 lệnh trên để xác nhận đường vẫn thông trước
khi export STL bản in chính thức.

### A2. Kiểm mảnh rời + độ dày thành — `verify_flow_tray.py`

```bash
python -m pip install trimesh rtree numpy   # 1 lần duy nhất
PYTHONIOENCODING=utf-8 python -X utf8 openscad/verify/verify_flow_tray.py openscad/print/print_flow_tray.stl
```

Kiểm 2 việc mà `export-stl.sh` KHÔNG bắt được (cả 2 đều xuất STL "manifold sạch"
dù sai hoàn toàn về công năng — xem PHẦN D trong
`docs/research/2026-07-23-khay-lang-song-nghien-cuu-hop-nhat.md`):
1. **Số khối liên thông** (`body_count`) — phải = 1. >1 nghĩa là có mảnh KHÔNG
   gắn liền vào thân chính (đúng loại lỗi vách baffle từng trôi nổi).
2. **Quét độ dày thành** bằng ray casting pháp tuyến (heuristic, có lọc hit giả
   trên mặt cong nhiều facet — xem comment trong script). Có 2 vùng NGẦM ĐỊNH
   mỏng theo thiết kế nên đừng hoảng khi thấy chúng trong output: gờ kê đĩa
   acrylic (`ledge_plate_t=1.0mm`, ghi rõ "cho phép" trong `constants.scad`) và
   mép cắt phẳng đáy hở tại miệng loe (z=0, chủ ý theo comment đầu
   `flow_tray_003.scad`).

**Kết quả hiện tại: `body_count=1`, `watertight=True`, không điểm nào dưới
0.5mm ngoài 2 vùng ngầm định ở trên.**

### A3. Mặt cắt ngang để soi tay 1 vùng cụ thể — `cross_section_check_001.scad`

Khi A2 báo nghi ngờ ở 1 toạ độ cụ thể, đổi `CUT_Z` trong file này rồi render
top-down để nhìn trực tiếp mặt cắt tại độ cao đó — đúng kỹ thuật
`projection(cut=true)` mà PHẦN D dùng để tìm ra lỗi miệng loe bị bịt trước đây.

---

## PHẦN B — Mô phỏng dòng chảy thật bằng CFD (SimScale)

**Việc này KHÔNG làm được bằng OpenSCAD.** 3 công cụ ở PHẦN A chỉ xác nhận
hình học tĩnh — không cái nào biết nước có thực sự dập sóng trong 2 giây hay
cổng ra có bị "ực nước" (xoáy hút khí) hay không. Đó là 2 câu hỏi CFD mới trả
lời được (docs/research §2 và §4).

Chọn **SimScale** (không phải OpenFOAM cài local) vì máy đang dùng Windows —
OpenFOAM cần WSL2/Linux, SimScale chạy thẳng trên trình duyệt, có gói
Community miễn phí (dự án public), không cần cài gì.

### B0. 2 file STL đã chuẩn bị sẵn

- **`fluid_domain_001.stl`** — hình dạng khối NƯỚC TĨNH lúc settle (chỉ để đối
  chiếu bằng mắt, KHÔNG nạp thẳng vào SimScale).
- **`fluid_domain_full_001.stl`** — khối KHÔNG GIAN TÍNH TOÁN đầy đủ (nước +
  khoảng khí phía trên, cao tới mép khay `tray_depth=12mm`) + ống thẳng nối dài
  20mm ở cả 2 đầu vào/ra (để đặt biên inlet/outlet ổn định, không sát ngay khúc
  cua). **Đây là file nạp vào SimScale.**

Cả 2 đều dựng bằng cách: lấy 1 vùng bao rộng rãi rồi TRỪ đi chính khối nhựa
`flow_tray()` — đảm bảo khớp tuyệt đối với hình học in thật, không vẽ tay lại.
Khi đổi `constants.scad`, chạy lại:
```bash
bash .claude/skills/export-stl/scripts/export-stl.sh openscad/verify/fluid_domain_full_001.scad --output openscad/verify/fluid_domain_full_001.stl
```
(Cảnh báo non-manifold nhẹ — 2 cạnh lỗi trên >22000 cạnh, đúng vị trí mép cắt
phẳng z=0 tại miệng loe đã biết ở PHẦN A2 — không đáng lo, công cụ sửa mesh của
SimScale xử lý được lúc nạp.)

### B1. Tạo tài khoản + tạo project

1. simscale.com → đăng ký tài khoản (gói Community — dự án sẽ ở chế độ public,
   ai cũng xem được, chấp nhận được cho đồ án học tập).
2. New Project → Import geometry → upload `fluid_domain_full_001.stl`.

### B2. Loại mô phỏng

Chọn **Multiphase (Volume of Fluid / free surface)** — đây là bài toán 2 pha
khí-nước có mặt thoáng tự do (dòng hở, không phải ống kín), đúng loại bài toán
VOF chuẩn. (Tên nút chính xác có thể đổi theo phiên bản UI — tìm từ khoá
"Multiphase" hoặc "Free surface" trong danh sách simulation type.)

### B3. Mesh

Dùng mesh tự động trước, rồi thêm 1 vùng tinh chỉnh (refinement region) quanh
cụm chống sóng — kích thước ô lưới nhỏ nhất cần thấy được khe hẹp nhất thiết kế
là `baffle_corridor=3.0mm`, nên đặt ô lưới ~0.4-0.6mm ở đó (quy tắc chung: ≥5 ô
cắt ngang khe hẹp nhất mới tin được kết quả):

- Vùng tinh chỉnh: hộp bao quanh gốc toạ độ, x∈[-25,25], y∈[-25,25], z∈[0,8]
  (trùm vách cong + miệng loe).

### B4. Biên (boundary conditions)

Xác định các mặt bằng toạ độ (khớp `flow_tray_003.scad`, gốc tại tâm sàn khay):

| Mặt | Toạ độ nhận dạng | Loại biên |
|---|---|---|
| Đầu ống vào (mặt tròn Ø6, xa nhất phía −X) | x ≈ −57 | **Velocity inlet** |
| Đầu ống ra (mặt tròn Ø6, xa nhất phía +X) | x ≈ +50 | **Pressure outlet** (hoặc velocity outlet cùng lưu lượng — bơm hút ở đây, nhưng pressure outlet đơn giản hơn cho lần chạy đầu) |
| Mặt trên cùng (z = 12, miệng khay hở) | z = 12 | **Opening** (áp suất khí quyển, 2 chiều — khí có thể ra/vào tự do) |
| Còn lại (thành khay, vách cong, miệng loe...) | — | **Wall, no-slip** |

**Vận tốc inlet** — suy từ lưu lượng bơm RS365 CHƯA ĐO thật (datasheet chung
1.5–2.2 L/min, xem `docs/research/...`), tiết diện lòng ống Ø6mm = 28.3mm²:

```
v = Q / A
1.5 L/min → v ≈ 0.88 m/s
2.2 L/min → v ≈ 1.30 m/s
```

Chạy thử với **v = 1.0 m/s không đổi** trước (đơn giản, xác nhận setup chạy
được đã). Muốn xét đúng nghi vấn cộng hưởng ở §2 tài liệu nghiên cứu, đổi sang
vận tốc DAO ĐỘNG theo thời gian (SimScale cho nhập biểu thức theo `t`):

```
v(t) = v_mean * (1 + 0.4 * sin(2*pi*f_pump*t))
```
với `f_pump` thử lần lượt 5Hz, 7Hz, 10Hz (đúng dải chưa đo thật trong tài liệu
— CFD cho phép quét thử nhiều giá trị mà KHÔNG cần đợi đo bơm thật trước, dù
vẫn cần đo thật sau này để xác nhận số nào đúng).

### B5. Điều kiện ban đầu (initial conditions)

VOF cần biết pha ban đầu ở đâu là nước, đâu là khí — làm NGAY TRONG SimScale
(không cần dựng lại geometry): chọn "Initial conditions" → gán phase fraction
= 1 (nước) cho vùng `z < 6`, = 0 (khí) cho `z ≥ 6`. Trùng khớp `water_depth=6`
trong `constants.scad`.

### B6. Cài đặt chạy (transient)

- **Bước thời gian (time step):** đủ nhỏ để thấy được dao động bơm — nếu thử
  `f_pump=10Hz`, cần ≥20 bước/chu kỳ ⇒ `dt ≤ 0.005s`. An toàn hơn: bật
  adaptive time step nếu SimScale hỗ trợ.
- **Thời gian mô phỏng:** tối thiểu hết 1 chu kỳ Stop-Flow theo firmware thật
  (`firmware/pump_pwm_test/pump_pwm_test.ino`): `fillMs=5000` + `rampDownMs=350`
  + `settleMs=2000` ⇒ chạy **≥ 7.5 giây mô phỏng**.

### B7. Đọc kết quả — trả lời đúng 2 câu hỏi đang treo

1. **Sóng có dập trong 2s SETTLING không?** Đặt 1 "probe point" tại tâm khay
   (x=0,y=0) theo dõi độ cao mặt thoáng (phase fraction=0.5) theo thời gian.
   Sau mốc `fillMs+rampDownMs≈5.35s` (bơm đã tắt hẳn), xem biên độ dao động mặt
   nước có tắt dần về gần 0 trước mốc `+2s` (t≈7.35s) hay không. Nếu KHÔNG dập
   kịp → đúng nghi vấn của tài liệu nghiên cứu §2, cần tăng `baffle_h`/đổi
   `baffle_angle`/xét lại T-Dome (§6, hiện đang hoãn).
2. **Cổng ra có "ực nước" không?** Xem trường vận tốc/streamline quanh miệng
   loe lúc `v_mean` cao (pha FILLING) — tìm dấu hiệu xoáy phễu hút khí xuống
   theo lòng ống (vortex core kéo dài từ mặt thoáng xuống miệng loe). Nếu thấy
   → cần hạ `v_mean` (tức hạ % PWM cruise-duty trong firmware) tới khi hết —
   **đây chính là cách CHỐT SỐ % cruise-duty (mục #7 còn tồn đọng trong PHẦN E
   research doc) bằng mô phỏng TRƯỚC khi cần đo tay trên bơm thật**, dù vẫn nên
   đối chiếu lại với bơm thật sau khi có.

### B8. Vòng lặp "sửa trước khi in"

1. Đổi 1 tham số nghi ngờ trong `constants.scad` (vd `baffle_h`, `baffle_angle`,
   `dc_jack_hole_d`...).
2. Chạy lại A1 (probe) — xác nhận đường vẫn thông cho hạt 2mm.
3. Chạy lại A2 (trimesh) — xác nhận vẫn 1 khối, không thành nào mới mỏng bất
   thường.
4. Export lại `fluid_domain_full_001.stl`, nạp lại SimScale, chạy lại B4-B7 —
   xác nhận sóng vẫn dập kịp / cổng ra vẫn không ực nước.
5. Chỉ khi cả 4 bước trên đều pass mới export bản in `print_flow_tray.stl`
   chính thức.

## Giới hạn cần biết

- A1/A2 là kiểm hình học CẦN, không phải ĐỦ — xác nhận đường thông/không mảnh
  rời, không mô phỏng vật lý dòng chảy.
- CFD (PHẦN B) là mô hình SỐ, không phải đo thật — độ chính xác phụ thuộc trực
  tiếp vào 2 số CHƯA ĐO thật trong tài liệu nghiên cứu (tần số nhịp màng bơm,
  lưu lượng thật). Dùng CFD để LOẠI TRỪ SỚM các thiết kế rõ ràng sai (sóng
  không dập nổi trong biên độ lớn, xoáy rõ rệt ở mọi vận tốc thử) và THU HẸP
  khoảng cần thử khi có bơm thật — không thay thế hoàn toàn việc đo/in thử
  cuối cùng.

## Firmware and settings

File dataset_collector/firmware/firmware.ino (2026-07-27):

#include <esp_camera.h>
#include <esp_task_wdt.h>
#include <WiFi.h>
#include "src/parsebytes.h"

// === AQUA SCOPE: đã cắt OTA / mDNS / NTP / captive portal ====================
// Bản gốc easytarget nạp thêm ArduinoOTA, ESPmDNS, DNSServer, WiFiUdp, time.h.
// Không cái nào đụng vào đường camera, nhưng mỗi cái đều chạy task nền ăn heap
// — thứ mà ESP32-CAM vốn đã thiếu khi chụp UXGA. Trạm này nạp qua USB, dùng IP
// trực tiếp, và laptop mới là nơi đóng dấu thời gian, nên cả 4 đều thừa.
//
// Các biến cờ (otaEnabled / haveTime / captivePortal) được GIỮ LẠI và đặt cứng
// false: app_httpd.cpp tham chiếu tới chúng, giữ vậy thì file đó không phải sửa
// một dòng nào — đúng tinh thần "copy y hệt để tránh lỗi".
// ============================================================================


/* This sketch is a extension/expansion/reork of the 'official' ESP32 Camera example
 *  sketch from Expressif:
 *  https://github.com/espressif/arduino-esp32/tree/master/libraries/ESP32/examples/Camera/CameraWebServer
 *
 *  It is modified to allow control of Illumination LED Lamps's (present on some modules),
 *  greater feedback via a status LED, and the HTML contents are present in plain text
 *  for easy modification.
 *
 *  A camera name can now be configured, and wifi details can be stored in an optional
 *  header file to allow easier updated of the repo.
 *
 *  The web UI has had changes to add the lamp control, rotation, a standalone viewer,
 *  more feeedback, new controls and other tweaks and changes,
 * note: Make sure that you have either selected ESP32 AI Thinker,
 *       or another board which has PSRAM enabled to use high resolution camera modes
 */


/*
 *  FOR NETWORK AND HARDWARE SETTINGS COPY OR RENAME 'myconfig.sample.h' TO 'myconfig.h' AND EDIT THAT.
 *
 * By default this sketch will assume an AI-THINKER ESP-CAM and create
 * an accesspoint called "ESP32-CAM-CONNECT" (password: "InsecurePassword")
 *
 */

// Primary config, or defaults.
#if __has_include("myconfig.h")
    struct station { const char ssid[65]; const char password[65]; const bool dhcp;};  // do no edit
    #include "myconfig.h"
#else
    #warning "Using Defaults: Copy myconfig.sample.h to myconfig.h and edit that to use your own settings"
    #define WIFI_AP_ENABLE
    #define CAMERA_MODEL_AI_THINKER
    struct station { const char ssid[65]; const char password[65]; const bool dhcp;}
    stationList[] = {{"ESP32-CAM-CONNECT","InsecurePassword", true}};
#endif

// Upstream version string
#include "src/version.h"

// Pin Mappings
#include "camera_pins.h"

// Camera config structure
camera_config_t config;

// Internal filesystem (SPIFFS)
// used for non-volatile camera settings
#include "storage.h"

// Sketch Info
int sketchSize;
int sketchSpace;
String sketchMD5;

// Start with accesspoint mode disabled, wifi setup will activate it if
// no known networks are found, and WIFI_AP_ENABLE has been defined
bool accesspoint = false;

// IP address, Netmask and Gateway, populated when connected
IPAddress ip;
IPAddress net;
IPAddress gw;

// Declare external function from app_httpd.cpp
extern void startCameraServer(int hPort, int sPort);
extern void serialDump();

// Names for the Camera. (set these in myconfig.h)
#if defined(CAM_NAME)
    char myName[] = CAM_NAME;
#else
    char myName[] = "ESP32 camera server";
#endif

#if defined(MDNS_NAME)
    char mdnsName[] = MDNS_NAME;
#else
    char mdnsName[] = "esp32-cam";
#endif

// Ports for http and stream (override in myconfig.h)
#if defined(HTTP_PORT)
    int httpPort = HTTP_PORT;
#else
    int httpPort = 80;
#endif

#if defined(STREAM_PORT)
    int streamPort = STREAM_PORT;
#else
    int streamPort = 81;
#endif

#if !defined(WIFI_WATCHDOG)
    #define WIFI_WATCHDOG 15000
#endif

// Number of known networks in stationList[]
int stationCount = sizeof(stationList)/sizeof(stationList[0]);

// If we have AP mode enabled, ignore first entry in the stationList[]
#if defined(WIFI_AP_ENABLE)
    int firstStation = 1;
#else
    int firstStation = 0;
#endif

// Select between full and simple index as the default.
#if defined(DEFAULT_INDEX_FULL)
    char default_index[] = "full";
#else
    char default_index[] = "simple";
#endif

// Captive portal đã cắt; giữ cờ cho app_httpd.cpp tham chiếu.
bool captivePortal = false;
char apName[64] = "Undefined";

// The app and stream URLs
char httpURL[64] = {"Undefined"};
char streamURL[64] = {"Undefined"};

// Counters for info screens and debug
int8_t streamCount = 0;          // Number of currently active streams
unsigned long streamsServed = 0; // Total completed streams
unsigned long imagesServed = 0;  // Total image requests

// This will be displayed to identify the firmware
char myVer[] PROGMEM = __DATE__ " @ " __TIME__;

// This will be set to the sensors PID (identifier) during initialisation
//camera_pid_t sensorPID;
int sensorPID;

// Camera module bus communications frequency.
// Originally: config.xclk_freq_mhz = 20000000, but this lead to visual artifacts on many modules.
// See https://github.com/espressif/esp32-camera/issues/150#issuecomment-726473652 et al.
#if !defined (XCLK_FREQ_MHZ)
    unsigned long xclk = 8;
#else
    unsigned long xclk = XCLK_FREQ_MHZ;
#endif

// initial rotation
// can be set in myconfig.h
#if !defined(CAM_ROTATION)
    #define CAM_ROTATION 0
#endif
int myRotation = CAM_ROTATION;

// minimal frame duration in ms, effectively 1/maxFPS
#if !defined(MIN_FRAME_TIME)
    #define MIN_FRAME_TIME 0
#endif
int minFrameTime = MIN_FRAME_TIME;

// Illumination LAMP and status LED
#if defined(LAMP_DISABLE)
    int lampVal = -1; // lamp is disabled in config
#elif defined(LAMP_PIN)
    #if defined(LAMP_DEFAULT)
        int lampVal = constrain(LAMP_DEFAULT,0,100); // initial lamp value, range 0-100
    #else
        int lampVal = 0; //default to off
    #endif
#else
    int lampVal = -1; // no lamp pin assigned
#endif

#if defined(LED_DISABLE)
    #undef LED_PIN    // undefining this disables the notification LED
#endif

bool autoLamp = false;         // Automatic lamp (auto on while camera running)

int lampChannel = 7;           // a free PWM channel (some channels used by camera)
const int pwmfreq = 50000;     // 50K pwm frequency
const int pwmresolution = 9;   // duty cycle bit range
const int pwmMax = pow(2,pwmresolution)-1;

#if defined(NO_FS)
    bool filesystem = false;
#else
    bool filesystem = true;
#endif

// OTA và NTP đã cắt. Giữ biến vì app_httpd.cpp in chúng ra trang trạng thái.
bool otaEnabled = false;
char otaPassword[] = "";
bool haveTime = false;

// Critical error string; if set during init (camera hardware failure) it
// will be returned for all http requests
String critERR = "";

// Debug flag for stream and capture data
bool debugData;

void debugOn() {
    debugData = true;
    Serial.println("Camera debug data is enabled (send 'd' for status dump, or any other char to disable debug)");
}

void debugOff() {
    debugData = false;
    Serial.println("Camera debug data is disabled (send 'd' for status dump, or any other char to enable debug)");
}

// Serial input (debugging controls)
void handleSerial() {
    if (Serial.available()) {
        char cmd = Serial.read();
        if (cmd == 'd' ) {
            serialDump();
        } else {
            if (debugData) debugOff();
            else debugOn();
        }
    }
    while (Serial.available()) Serial.read();  // chomp the buffer
}

// Notification LED
void flashLED(int flashtime) {
#if defined(LED_PIN)                // If we have it; flash it.
    digitalWrite(LED_PIN, LED_ON);  // On at full power.
    delay(flashtime);               // delay
    digitalWrite(LED_PIN, LED_OFF); // turn Off
#else
    return;                         // No notifcation LED, do nothing, no delay
#endif
}

// Lamp Control
void setLamp(int newVal) {
#if defined(LAMP_PIN)
    if (newVal != -1) {
        // Apply a logarithmic function to the scale.
        int brightness = round((pow(2,(1+(newVal*0.02)))-2)/6*pwmMax);
        ledcWrite(LAMP_PIN, brightness);  // core 3.x: ledcWrite theo PIN, không theo channel
        Serial.print("Lamp: ");
        Serial.print(newVal);
        Serial.print("%, pwm = ");
        Serial.println(brightness);
    }
#endif
}

// NTP đã cắt. Hàm giữ lại làm no-op vì app_httpd.cpp khai báo extern và gọi nó
// (chỉ khi haveTime == true, tức là không bao giờ).
void printLocalTime(bool extraData=false) {
    (void)extraData;
}

void calcURLs() {
    // Set the URL's
    #if defined(URL_HOSTNAME)
        if (httpPort != 80) {
            sprintf(httpURL, "http://%s:%d/", URL_HOSTNAME, httpPort);
        } else {
            sprintf(httpURL, "http://%s/", URL_HOSTNAME);
        }
        sprintf(streamURL, "http://%s:%d/", URL_HOSTNAME, streamPort);
    #else
        Serial.println("Setting httpURL");
        if (httpPort != 80) {
            sprintf(httpURL, "http://%d.%d.%d.%d:%d/", ip[0], ip[1], ip[2], ip[3], httpPort);
        } else {
            sprintf(httpURL, "http://%d.%d.%d.%d/", ip[0], ip[1], ip[2], ip[3]);
        }
        sprintf(streamURL, "http://%d.%d.%d.%d:%d/", ip[0], ip[1], ip[2], ip[3], streamPort);
    #endif
}

void StartCamera() {
    // Populate camera config structure with hardware and other defaults
    config.ledc_channel = LEDC_CHANNEL_0;
    config.ledc_timer = LEDC_TIMER_0;
    config.pin_d0 = Y2_GPIO_NUM;
    config.pin_d1 = Y3_GPIO_NUM;
    config.pin_d2 = Y4_GPIO_NUM;
    config.pin_d3 = Y5_GPIO_NUM;
    config.pin_d4 = Y6_GPIO_NUM;
    config.pin_d5 = Y7_GPIO_NUM;
    config.pin_d6 = Y8_GPIO_NUM;
    config.pin_d7 = Y9_GPIO_NUM;
    config.pin_xclk = XCLK_GPIO_NUM;
    config.pin_pclk = PCLK_GPIO_NUM;
    config.pin_vsync = VSYNC_GPIO_NUM;
    config.pin_href = HREF_GPIO_NUM;
    config.pin_sccb_sda = SIOD_GPIO_NUM;
    config.pin_sccb_scl = SIOC_GPIO_NUM;
    config.pin_pwdn = PWDN_GPIO_NUM;
    config.pin_reset = RESET_GPIO_NUM;
    config.xclk_freq_hz = xclk * 1000000;
    config.pixel_format = PIXFORMAT_JPEG;
    // Low(ish) default framesize and quality
    config.frame_size = FRAMESIZE_SVGA;
    config.jpeg_quality = 12;
    config.fb_location = CAMERA_FB_IN_PSRAM;
    config.fb_count = 2;
    config.grab_mode = CAMERA_GRAB_LATEST;

    #if defined(CAMERA_MODEL_ESP_EYE)
        pinMode(13, INPUT_PULLUP);
        pinMode(14, INPUT_PULLUP);
    #endif

    // camera init
    esp_err_t err = esp_camera_init(&config);
    if (err != ESP_OK) {
        delay(100);  // need a delay here or the next serial o/p gets missed
        Serial.printf("\r\n\r\nCRITICAL FAILURE: Camera sensor failed to initialise.\r\n\r\n");
        Serial.printf("A full (hard, power off/on) reboot will probably be needed to recover from this.\r\n");
        Serial.printf("Meanwhile; this unit will reboot in 1 minute since these errors sometime clear automatically\r\n");
        // And set the error text for the UI
        critERR = "<h1>Error!</h1><hr><p>Camera module failed to initialise!</p><p>Please reset (power off/on) the camera.</p>";
        critERR += "<p>We will continue to reboot once per minute since this error sometimes clears automatically.</p>";
        // Start a 60 second watchdog timer (core 3.x API: reconfigure the already-running TWDT)
        esp_task_wdt_config_t twdt_cfg = { .timeout_ms = 60000, .idle_core_mask = 0, .trigger_panic = true };
        esp_task_wdt_reconfigure(&twdt_cfg);
        esp_task_wdt_add(NULL);
    } else {
        Serial.println("Camera init succeeded");

        // Get a reference to the sensor
        sensor_t * s = esp_camera_sensor_get();

        // Dump camera module, warn for unsupported modules.
        sensorPID = s->id.PID;
        switch (sensorPID) {
            case OV9650_PID: Serial.println("WARNING: OV9650 camera module is not properly supported, will fallback to OV2640 operation"); break;
            case OV7725_PID: Serial.println("WARNING: OV7725 camera module is not properly supported, will fallback to OV2640 operation"); break;
            case OV2640_PID: Serial.println("OV2640 camera module detected"); break;
            case OV3660_PID: Serial.println("OV3660 camera module detected"); break;
            default: Serial.println("WARNING: Camera module is unknown and not properly supported, will fallback to OV2640 operation");
        }

        // === AQUA SCOPE TEST OVERRIDE =====================================
        // Ep bien `sensorPID` (dung cho logic cua Aqua Scope: chon giao dien
        // + preset ben duoi) thanh OV3660, BAT KE chip that tra ve gi.
        //
        // AN TOAN vi day CHI la bien logic tang ung dung. Duong giao tiep
        // thuc voi sensor (cac ham s->set_*) da duoc esp32-camera gan dung
        // driver theo PID THAT ma no doc qua SCCB ngay trong esp_camera_init()
        // o tren - ep bien nay KHONG doi lai duong do.
        //
        // Dung khi: test giao dien index_ov3660.h ma khong can cam board that
        // co OV3660. KHONG dung khi chay that voi phan cung that - de vay se
        // ap preset OV3660 (vflip/brightness/saturation) len chip OV2640 that,
        // anh se bi sai chieu/sang mau khong dung y muon.
        //
        // Bo comment dong duoi de bat:
        // #define AQUA_FORCE_OV3660_UI
        #if defined(AQUA_FORCE_OV3660_UI)
            Serial.println("[AQUA TEST OVERRIDE] Ep sensorPID = OV3660 (bo qua nhan dien that)");
            sensorPID = OV3660_PID;
        #endif

        // OV3660 initial sensors are flipped vertically and colors are a bit saturated
        if (sensorPID == OV3660_PID) {
            s->set_vflip(s, 1);  //flip it back
            s->set_brightness(s, 1);  //up the blightness just a bit
            s->set_saturation(s, -2);  //lower the saturation
        }

        // M5 Stack Wide has special needs
        #if defined(CAMERA_MODEL_M5STACK_WIDE)
            s->set_vflip(s, 1);
            s->set_hmirror(s, 1);
        #endif

        // Config can override mirror and flip
        #if defined(H_MIRROR)
            s->set_hmirror(s, H_MIRROR);
        #endif
        #if defined(V_FLIP)
            s->set_vflip(s, V_FLIP);
        #endif

        // set initial frame rate
        #if defined(DEFAULT_RESOLUTION)
            s->set_framesize(s, DEFAULT_RESOLUTION);
        #endif

        /*
        * Add any other defaults you want to apply at startup here:
        * uncomment the line and set the value as desired (see the comments)
        *
        * these are defined in the esp headers here:
        * https://github.com/espressif/esp32-camera/blob/master/driver/include/sensor.h#L149
        */

        //s->set_framesize(s, FRAMESIZE_SVGA); // FRAMESIZE_[QQVGA|HQVGA|QVGA|CIF|VGA|SVGA|XGA|SXGA|UXGA|QXGA(ov3660)]);
        //s->set_quality(s, val);       // 10 to 63
        //s->set_brightness(s, 0);      // -2 to 2
        //s->set_contrast(s, 0);        // -2 to 2
        //s->set_saturation(s, 0);      // -2 to 2
        //s->set_special_effect(s, 0);  // 0 to 6 (0 - No Effect, 1 - Negative, 2 - Grayscale, 3 - Red Tint, 4 - Green Tint, 5 - Blue Tint, 6 - Sepia)
        //s->set_whitebal(s, 1);        // aka 'awb' in the UI; 0 = disable , 1 = enable
        //s->set_awb_gain(s, 1);        // 0 = disable , 1 = enable
        //s->set_wb_mode(s, 0);         // 0 to 4 - if awb_gain enabled (0 - Auto, 1 - Sunny, 2 - Cloudy, 3 - Office, 4 - Home)
        //s->set_exposure_ctrl(s, 1);   // 0 = disable , 1 = enable
        //s->set_aec2(s, 0);            // 0 = disable , 1 = enable
        //s->set_ae_level(s, 0);        // -2 to 2
        //s->set_aec_value(s, 300);     // 0 to 1200
        //s->set_gain_ctrl(s, 1);       // 0 = disable , 1 = enable
        //s->set_agc_gain(s, 0);        // 0 to 30
        //s->set_gainceiling(s, (gainceiling_t)0);  // 0 to 6
        //s->set_bpc(s, 0);             // 0 = disable , 1 = enable
        //s->set_wpc(s, 1);             // 0 = disable , 1 = enable
        //s->set_raw_gma(s, 1);         // 0 = disable , 1 = enable
        //s->set_lenc(s, 1);            // 0 = disable , 1 = enable
        //s->set_hmirror(s, 0);         // 0 = disable , 1 = enable
        //s->set_vflip(s, 0);           // 0 = disable , 1 = enable
        //s->set_dcw(s, 1);             // 0 = disable , 1 = enable
        //s->set_colorbar(s, 0);        // 0 = disable , 1 = enable
    }
    // We now have camera with default init
}
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
void loop() {
    /*
     *  Just loop forever, reconnecting Wifi As necesscary in client mode
     * The stream and URI handler processes initiated by the startCameraServer() call at the
     * end of setup() will handle the camera and UI processing from now on.
    */
    if (accesspoint) {
        // Accespoint is permanently up, so just loop, servicing the captive portal as needed
        // Rather than loop forever, follow the watchdog, in case we later add auto re-scan.
        unsigned long start = millis();
        while (millis() - start < WIFI_WATCHDOG ) {
            delay(100);
            handleSerial();
        }
    } else {
        // client mode can fail; so reconnect as appropriate
        static bool warned = false;
        if (WiFi.status() == WL_CONNECTED) {
            // We are connected, wait a bit and re-check
            if (warned) {
                // Tell the user if we have just reconnected
                Serial.println("WiFi reconnected");
                warned = false;
            }
            // loop here for WIFI_WATCHDOG, turning debugData true/false depending on serial input..
            unsigned long start = millis();
            while (millis() - start < WIFI_WATCHDOG ) {
                delay(100);
                handleSerial();
            }
        } else {
            // disconnected; attempt to reconnect
            if (!warned) {
                // Tell the user if we just disconnected
                WiFi.disconnect();  // ensures disconnect is complete, wifi scan cleared
                Serial.println("WiFi disconnected, retrying");
                warned = true;
            }
            WifiSetup();
        }
    }
}

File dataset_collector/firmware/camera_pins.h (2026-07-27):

 /*
 *   Pin definitions for some common ESP-CAM modules
 *
 *   Select the module to use in myconfig.h
 *   Defaults to AI-THINKER CAM module
 *
 */
#if defined(CAMERA_MODEL_AI_THINKER)
  //
  // AI Thinker
  // https://github.com/SeeedDocument/forum_doc/raw/master/reg/ESP32_CAM_V1.6.pdf
  //
  #define PWDN_GPIO_NUM     32
  #define RESET_GPIO_NUM    -1
  #define XCLK_GPIO_NUM      0
  #define SIOD_GPIO_NUM     26
  #define SIOC_GPIO_NUM     27
  #define Y9_GPIO_NUM       35
  #define Y8_GPIO_NUM       34
  #define Y7_GPIO_NUM       39
  #define Y6_GPIO_NUM       36
  #define Y5_GPIO_NUM       21
  #define Y4_GPIO_NUM       19
  #define Y3_GPIO_NUM       18
  #define Y2_GPIO_NUM        5
  #define VSYNC_GPIO_NUM    25
  #define HREF_GPIO_NUM     23
  #define PCLK_GPIO_NUM     22
  #define LED_PIN           33 // Status led
  #define LED_ON           LOW // - Pin is inverted.
  #define LED_OFF         HIGH //
  #define LAMP_PIN           4 // LED FloodLamp.

#elif defined(CAMERA_MODEL_WROVER_KIT)
  //
  // ESP WROVER
  // https://dl.espressif.com/dl/schematics/ESP-WROVER-KIT_SCH-2.pdf
  //
  #define PWDN_GPIO_NUM    -1
  #define RESET_GPIO_NUM   -1
  #define XCLK_GPIO_NUM    21
  #define SIOD_GPIO_NUM    26
  #define SIOC_GPIO_NUM    27
  #define Y9_GPIO_NUM      35
  #define Y8_GPIO_NUM      34
  #define Y7_GPIO_NUM      39
  #define Y6_GPIO_NUM      36
  #define Y5_GPIO_NUM      19
  #define Y4_GPIO_NUM      18
  #define Y3_GPIO_NUM       5
  #define Y2_GPIO_NUM       4
  #define VSYNC_GPIO_NUM   25
  #define HREF_GPIO_NUM    23
  #define PCLK_GPIO_NUM    22
  #define LED_PIN           2 // A status led on the RGB; could also use pin 0 or 4
  #define LED_ON         HIGH //
  #define LED_OFF         LOW //
  // #define LAMP_PIN          x // No LED FloodLamp.

#elif defined(CAMERA_MODEL_ESP_EYE)
  //
  // ESP-EYE
  // https://twitter.com/esp32net/status/1085488403460882437
  #define PWDN_GPIO_NUM    -1
  #define RESET_GPIO_NUM   -1
  #define XCLK_GPIO_NUM     4
  #define SIOD_GPIO_NUM    18
  #define SIOC_GPIO_NUM    23
  #define Y9_GPIO_NUM      36
  #define Y8_GPIO_NUM      37
  #define Y7_GPIO_NUM      38
  #define Y6_GPIO_NUM      39
  #define Y5_GPIO_NUM      35
  #define Y4_GPIO_NUM      14
  #define Y3_GPIO_NUM      13
  #define Y2_GPIO_NUM      34
  #define VSYNC_GPIO_NUM    5
  #define HREF_GPIO_NUM    27
  #define PCLK_GPIO_NUM    25
  #define LED_PIN          21 // Status led
  #define LED_ON         HIGH //
  #define LED_OFF         LOW //
  // #define LAMP_PIN          x // No LED FloodLamp.

#elif defined(CAMERA_MODEL_M5STACK_PSRAM)
  //
  // ESP32 M5STACK
  //
  #define PWDN_GPIO_NUM     -1
  #define RESET_GPIO_NUM    15
  #define XCLK_GPIO_NUM     27
  #define SIOD_GPIO_NUM     25
  #define SIOC_GPIO_NUM     23
  #define Y9_GPIO_NUM       19
  #define Y8_GPIO_NUM       36
  #define Y7_GPIO_NUM       18
  #define Y6_GPIO_NUM       39
  #define Y5_GPIO_NUM        5
  #define Y4_GPIO_NUM       34
  #define Y3_GPIO_NUM       35
  #define Y2_GPIO_NUM       32
  #define VSYNC_GPIO_NUM    22
  #define HREF_GPIO_NUM     26
  #define PCLK_GPIO_NUM     21
  // M5 Stack status/illumination LED details unknown/unclear
  // #define LED_PIN            x // Status led
  // #define LED_ON          HIGH //
  // #define LED_OFF          LOW //
  // #define LAMP_PIN          x  // LED FloodLamp.

#elif defined(CAMERA_MODEL_M5STACK_V2_PSRAM)
  //
  // ESP32 M5STACK V2
  //
  #define PWDN_GPIO_NUM     -1
  #define RESET_GPIO_NUM    15
  #define XCLK_GPIO_NUM     27
  #define SIOD_GPIO_NUM     22
  #define SIOC_GPIO_NUM     23
  #define Y9_GPIO_NUM       19
  #define Y8_GPIO_NUM       36
  #define Y7_GPIO_NUM       18
  #define Y6_GPIO_NUM       39
  #define Y5_GPIO_NUM        5
  #define Y4_GPIO_NUM       34
  #define Y3_GPIO_NUM       35
  #define Y2_GPIO_NUM       32
  #define VSYNC_GPIO_NUM    25
  #define HREF_GPIO_NUM     26
  #define PCLK_GPIO_NUM     21
  // M5 Stack status/illumination LED details unknown/unclear
  // #define LED_PIN            x // Status led
  // #define LED_ON          HIGH //
  // #define LED_OFF          LOW //
  // #define LAMP_PIN          x  // LED FloodLamp.

#elif defined(CAMERA_MODEL_M5STACK_WIDE)
  //
  // ESP32 M5STACK WIDE
  //
  #define PWDN_GPIO_NUM     -1
  #define RESET_GPIO_NUM    15
  #define XCLK_GPIO_NUM     27
  #define SIOD_GPIO_NUM     22
  #define SIOC_GPIO_NUM     23
  #define Y9_GPIO_NUM       19
  #define Y8_GPIO_NUM       36
  #define Y7_GPIO_NUM       18
  #define Y6_GPIO_NUM       39
  #define Y5_GPIO_NUM        5
  #define Y4_GPIO_NUM       34
  #define Y3_GPIO_NUM       35
  #define Y2_GPIO_NUM       32
  #define VSYNC_GPIO_NUM    25
  #define HREF_GPIO_NUM     26
  #define PCLK_GPIO_NUM     21
  // M5 Stack status/illumination LED details unknown/unclear
  // #define LED_PIN            x // Status led
  // #define LED_ON          HIGH //
  // #define LED_OFF          LOW //
  // #define LAMP_PIN          x  // LED FloodLamp.
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

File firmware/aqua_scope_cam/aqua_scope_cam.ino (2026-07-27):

/*
 * ============================================================================
 *  Aqua Scope — Firmware camera cho XIAO ESP32-S3 Sense (OV3660, 3MP)
 * ============================================================================
 *  Mục tiêu: chụp ảnh BACKLIT SILHOUETTE (nền sáng đều, hạt = bóng đen) để
 *  đếm & đo kích thước hạt rác 1-5mm. KHÔNG phải firmware kính hiển vi.
 *
 *  Điểm khác biệt so với firmware Matchboxscope:
 *   - Ép PHƠI SÁNG THỦ CÔNG: TẮT AEC / AEC-DSP / AGC, đặt Gain=0 + Exposure thấp
 *     -> nền không bị "cháy trắng" (đây là lỗi kinh điển khi để auto).
 *   - LƯU CỨNG cấu hình vào flash (NVS/Preferences): cắm điện là chạy đúng thông
 *     số đã chỉnh, không cần chỉnh lại.
 *   - Một selector ĐỘ PHÂN GIẢI duy nhất (QVGA..QXGA), đổi tự do khi test qua web
 *     hoặc serial; dùng chung cho cả stream lẫn chụp. OV3660 là cảm biến 3MP nên
 *     có thể lên tới QXGA 2048x1536 (OV2640 chỉ UXGA).
 *   - Chỉnh qua Web UI (slider trực quan) HOẶC lệnh Serial.
 *   - Có sẵn hook runVision() để nhúng computer vision on-device về sau.
 *
 *  Cấu hình board trong Arduino IDE:
 *   - Board:  "XIAO_ESP32S3"  (gói: esp32 by Espressif >= 3.0)
 *   - PSRAM:  "OPI PSRAM"  (BẮT BUỘC bật, nếu không camera không init được)
 *   - Partition: "Huge APP (3MB No OTA/1MB SPIFFS)" cho thoải mái
 * ============================================================================
 */

#include "esp_camera.h"
#include "camera_pins.h"
#include <WiFi.h>
#include <Preferences.h>
#include "esp_http_server.h"

// ----------------------------------------------------------------------------
// 1) WIFI — mặc định chạy Access Point (không cần router). Nối wifi "AquaScope"
//    rồi mở http://192.168.4.1  . Muốn nối vào router nhà thì đặt USE_STA = true.
// ----------------------------------------------------------------------------
#define USE_STA         false
const char* STA_SSID  = "TEN_WIFI_NHA";
const char* STA_PASS  = "MAT_KHAU_WIFI";
const char* AP_SSID   = "AquaScope";
const char* AP_PASS   = "aquascope";   // >= 8 ký tự

// ----------------------------------------------------------------------------
// 2) CẤU HÌNH — được nạp từ flash lúc boot; chỉnh runtime rồi 'save' để ghi cứng
// ----------------------------------------------------------------------------
struct CamConfig {
  int  exposure;       // AEC value thủ công 0..1200 (thấp = tối). Điểm chỉnh CHÍNH.
  int  gain;           // AGC gain thủ công 0..30. Backlit nên để 0.
  int  brightness;     // -2..2
  int  contrast;       // -2..2   (tăng nhẹ giúp tách bóng hạt khỏi nền)
  int  jpegQuality;    // 4(đẹp)..30(xấu). ~12 là hợp lý.
  int  grayscale;      // 1 = ép ảnh xám (tốt cho silhouette + CV), 0 = màu
  int  hmirror;        // 0/1
  int  vflip;          // 0/1
  int  framesize;      // độ phân giải dùng chung (giá trị enum framesize_t, xem HTML select)
};

// Giá trị mặc định — auto exposure/gain/white balance (không ép dark).
// Giữ const để nút "Khôi phục mặc định" luôn có bản gốc mà quay về.
const CamConfig DEFAULT_CFG = {
  .exposure   = 300,
  .gain       = 0,
  .brightness = 0,
  .contrast   = 0,
  .jpegQuality= 12,
  .grayscale  = 0,                       // 0 = ảnh màu (không ép xám)
  .hmirror    = 0,
  .vflip      = 1,                       // OV3660 mặc định ảnh lật ngược -> vflip=1 cho đúng chiều
  .framesize  = (int)FRAMESIZE_VGA,      // mặc định VGA; đổi tự do khi test (tới QXGA)
};

// Cấu hình đang chạy (khởi tạo từ mặc định, sẽ bị loadConfig() ghi đè nếu flash có dữ liệu)
CamConfig cfg = DEFAULT_CFG;

Preferences prefs;
httpd_handle_t httpServer   = NULL;   // port 80: điều khiển + chụp
httpd_handle_t streamServer = NULL;   // port 81: chỉ stream (tách riêng để không chặn điều khiển)

// CHẾ ĐỘ NGẮM/LẤY NÉT: khi true, tạm bật AEC/AGC/AWB + ảnh màu để nhìn rõ mà căn
// khung & lấy nét (đặt mẫu đúng ~4cm). KHÔNG lưu vào flash — chỉ là trạng thái
// runtime; boot lại luôn về chế độ backlit thủ công. Đây KHÔNG phải cấu hình chụp.
bool aimingMode = false;

// ----------------------------------------------------------------------------
// 3) LƯU / NẠP cấu hình từ flash (namespace "aquascope")
// ----------------------------------------------------------------------------
void loadConfig() {
  prefs.begin("aquascope", true);            // read-only
  if (prefs.isKey("exposure")) {
    cfg.exposure     = prefs.getInt("exposure",   cfg.exposure);
    cfg.gain         = prefs.getInt("gain",       cfg.gain);
    cfg.brightness   = prefs.getInt("bright",     cfg.brightness);
    cfg.contrast     = prefs.getInt("contrast",   cfg.contrast);
    cfg.jpegQuality  = prefs.getInt("jpegq",      cfg.jpegQuality);
    cfg.grayscale    = prefs.getInt("gray",       cfg.grayscale);
    cfg.hmirror      = prefs.getInt("hmirror",    cfg.hmirror);
    cfg.vflip        = prefs.getInt("vflip",      cfg.vflip);
    cfg.framesize    = prefs.getInt("fsize",      cfg.framesize);
    Serial.println("[cfg] Da nap cau hinh tu flash.");
  } else {
    Serial.println("[cfg] Chua co cau hinh trong flash -> dung mac dinh.");
  }
  prefs.end();
}

void saveConfig() {
  prefs.begin("aquascope", false);           // read-write
  prefs.putInt("exposure", cfg.exposure);
  prefs.putInt("gain",     cfg.gain);
  prefs.putInt("bright",   cfg.brightness);
  prefs.putInt("contrast", cfg.contrast);
  prefs.putInt("jpegq",    cfg.jpegQuality);
  prefs.putInt("gray",     cfg.grayscale);
  prefs.putInt("hmirror",  cfg.hmirror);
  prefs.putInt("vflip",    cfg.vflip);
  prefs.putInt("fsize",    cfg.framesize);
  prefs.end();
  Serial.println("[cfg] DA GHI CUNG cau hinh vao flash.");
}

// Khôi phục về mặc định: nạp lại DEFAULT_CFG, áp lên sensor, và XÓA cấu hình đã
// lưu trong flash -> lần sau reboot cũng chạy mặc định. Dùng khi lỡ chỉnh nhầm.
void resetConfig() {
  cfg = DEFAULT_CFG;
  applyConfig();
  sensor_t* s = esp_camera_sensor_get();
  if (s) s->set_framesize(s, (framesize_t)cfg.framesize);
  prefs.begin("aquascope", false);
  prefs.clear();
  prefs.end();
  Serial.println("[cfg] DA KHOI PHUC mac dinh + xoa cau hinh da luu trong flash.");
}
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

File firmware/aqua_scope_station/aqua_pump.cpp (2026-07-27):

/*
 * aqua_pump.cpp — implem cho aqua_pump.h.
 *
 * Port gần nguyên văn state machine + ramp từ pump_l298n_xiao.ino (bản test
 * L298N chạy trên XIAO ESP32-S3, nay đã gộp vào đây và xoá đi), đóng gói
 * thành module riêng thay vì nằm thẳng trong .ino.
 *
 * ---------------------------------------------------------------------------
 * KÊNH LEDC — vì sao aquaPumpInit() phải gọi SAU esp_camera_init()
 * ---------------------------------------------------------------------------
 * Driver esp32-camera tạo XCLK 20MHz bằng LEDC, nhưng nó cấu hình TRỰC TIẾP
 * qua ESP-IDF (ledc_timer_config/ledc_channel_config) nên KHÔNG đăng ký vào
 * Peripheral Manager của Arduino. Hệ quả: ledcAttach() tin rằng mọi kênh đều
 * rảnh và luôn cấp phát kênh 0 — đúng số kênh camera đang dùng.
 *
 * Trên ESP32 classic việc này KHÔNG xung đột, nhưng lý do rất hẹp: Arduino
 * đánh số kênh 0..7 = nhóm HIGH-speed, 8..15 = nhóm LOW-speed; esp32-camera
 * đặt XCLK ở nhóm LOW-speed. Hai nhóm là hai khối timer tách rời về phần
 * cứng, nên "kênh 0" của Arduino và "kênh 0" của camera là hai thứ khác nhau.
 *
 * Đây là sự TRÙNG HỢP có lợi, không phải bảo đảm của API. Vì vậy kết quả gắn
 * LEDC luôn được kiểm tra (g_pwmReady) thay vì tin là xong: nếu một phiên bản
 * core sau này đổi cách cấp phát, ta thấy lỗi ngay trên Serial chứ không phải
 * ngồi đoán vì sao bơm không chạy.
 */

#include "aqua_pump.h"

#include <Arduino.h>
#include "esp32-hal-ledc.h"

// ---------- Cấu hình chân & PWM ----------
static const int PUMP_PIN  = 13;
static const int PWM_FREQ  = 20000;  // 20kHz: ngoài ngưỡng nghe
static const int PWM_BITS  = 10;     // 10 bit → duty 0..1023
static const int PWM_MAX   = (1 << PWM_BITS) - 1;

// ---------- Trạng thái ----------
static PumpTiming g_timing;
static PumpPhase  g_phase       = PUMP_PHASE_FILLING;
static uint32_t   g_phaseStart  = 0;
static bool       g_autoRunning = false;  // TẮT mặc định — an toàn khi lắp/kiểm tra
static uint32_t   g_cycleCount  = 0;
static uint8_t    g_curDuty     = 0;      // % duty hiện tại
static bool       g_pwmReady    = false;  // ledcAttach đã thành công chưa

// Yêu cầu bật/tắt auto đến từ task khác (handler HTTP). aquaPumpTick() ở task
// loop() là nơi DUY NHẤT thực thi — xem ghi chú đồng thời trong aqua_pump.h.
// volatile: hai task đọc/ghi, cấm trình biên dịch giữ trong thanh ghi.
static volatile bool g_autoRequestPending = false;
static volatile bool g_autoRequestValue   = false;

// ---------- Helpers ----------

const char *pumpPhaseName(PumpPhase p) {
  switch (p) {
    case PUMP_PHASE_FILLING:  return "FILLING";
    case PUMP_PHASE_SETTLING: return "SETTLING";
    case PUMP_PHASE_FLUSHING: return "FLUSHING";
    case PUMP_PHASE_COOLDOWN: return "COOLDOWN";
  }
  return "?";
}
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

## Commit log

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2026-07-14 Redesign web system spec: split into SPEC + PLAN, fold in review fixes
    Replaces the combined web_plan.md (and the frontend-only design doc) with a
    superpowers-standard split:
    - specs/2026-07-14-web-system-design.md — whole-system SPEC (what/why,
    data contract, frontend design, testing strategy, boundaries)
    - plans/2026-07-14-web-system-plan.md — implementation PLAN (roadmap,
    module breakdown, verify scenarios)
    Bakes the code-review findings in as first-class requirements rather than
    afterthought patches: SEC-1 sample_code path-traversal validation,
    SEC-2 CSV formula-injection escaping, SEC-3 upload size cap, DATA-1 UTC
    datetime normalization (fixes the received-minus-captured delay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
2026-07-14 Harden ingest API: path traversal, upload limit, naive-UTC, field bounds
    Closes the SEC-1/SEC-3/DATA-1/SEC-4 gaps in web-system-design.md §6:
    sample_code is now allowlisted (^[A-Za-z0-9._-]{1,64}$) before it can reach
    the filesystem as a filename; oversized uploads are rejected with 413
    before the body is fully buffered; captured_at now requires a UTC offset
    and is normalized to naive-UTC to match received_at (so audit deltas
    aren't skewed by mixed tz-aware/naive datetimes); ParticleIn gets loose
    non-negative/range bounds. Added via strict TDD (failing test per
    requirement, then minimal fix).
2026-07-14 Fix SEC-1 newline bypass: fullmatch sample_code, tighten traversal test
    `^...$` + re.match accepted a trailing "\n" (Python `$` matches before a
    final newline and match() doesn't require consuming the whole string), so
    "evil\n" slipped past validation and reached image_file.write_bytes()
    outside the storage try/except — an uncaught OSError on Windows instead of
    a 422, and an unvalidated char reaching the filesystem (SEC-1 violation).
    Switch the validator to SAMPLE_CODE_PATTERN.fullmatch. Also strengthen the
    traversal test's escape assertion to check the resolved above-tmp_path
    target (the old tmp_path.rglob couldn't see an escape above tmp_path).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
2026-07-14 Harden read API: neutralize CSV formula injection, fix export N+1 query
    export.csv wrote user-controlled strings (device_id, batch_lot, label,
    sample_code) straight into CSV cells, risking formula injection when
    opened in a spreadsheet (SEC-2), and issued one particle query per
    sample in a loop (PERF-1). Add _csv_safe() to prefix a leading quote on
    any string cell starting with = + - @ TAB/CR, and fetch all particles
    for the matched sample set in a single IN() query grouped by sample_id
    in memory. Written TDD: new tests confirmed RED against the old code
    (4 particle-adjacent queries where 1 was expected; raw "=1+1" cell
    unprefixed) before the fix, then GREEN after.
    Spec: docs/superpowers/sp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
2026-07-14 Fix DATA-1 gaps: UTC sample_code timestamp, tz-aware from/to filters
    Final-review findings on the naive-UTC invariant were not total:
    _generate_sample_code() used local datetime.now(), so the human-readable
    sample_code disagreed with the naive-UTC captured_at/received_at columns
    by the machine's UTC offset. Separately, tz-aware `from`/`to` query
    params on GET /api/samples and /api/export.csv reached SQLite's DATETIME
    bind processor unnormalized, which drops tzinfo without converting to
    UTC first, silently shifting the filter window by the offset.
    Both fixed with a failing test first, then the fix:
    - ingest.py: datetime.now(timezone.utc) instead of datetime.now().
    - samples.py: added _to_nai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
2026-07-15 Add server-rendered QC dashboard (Module 5+6) with XSS fix + mobile nav
    Wires the dashboard/history/sample-detail/stream pages into the FastAPI
    backend (Jinja2 templates, inline-SVG charts, vanilla-JS bbox overlay and
    stream demo — no client charting lib or CDN so it stays offline-LAN).
    Hardening on top of the initial build:
    - Escape particle labels before embedding them in the bbox overlay's
    <script type="application/json"> block; a free-form label containing
    "</script>" could otherwise break out and inject markup (stored XSS).
    - Add a mobile nav strip so history/stream/dashboard stay reachable once
    the sidebar is hidden at <=900px.
    - Remove two unused code paths (_fmt_time, error_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
2026-07-15 feat(ml): naming helpers (sample_code + px_per_mm resolve)
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2026-07-15 fix(ml): warn on sample_code collisions; add detector unit + px-per-mm warning tests
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2026-07-18 fix(ml): clamp Roboflow bboxes to image, warn on unresolved predictions, actionable backend errors
2026-07-18 fix(ml): correct out-of-frame test fixture; label unused ingest.timeout_s
2026-07-19 fix(ml): probe must use the same outputs-envelope unwrapping as the run path
2026-07-19 feat(ml): send workflow parameters, making model_id swappable from config
    Switching to a newly trained model required editing the workflow in the
    Roboflow UI, because the client only ever sent the image. Two blockers:
    - The project base workflow hard-codes model_id and is platform-managed
    ("Cannot modify a project base workflow"), so it cannot take a parameter.
    The "...-logic" wrapper tried to work around this by passing model_id to
    an inner workflow that does not declare it -> 500 on every call.
    - Even with a fixed workflow, fetch_raw built inputs from the image alone.
    Replaced both workflows with "aqua-scope-infer", which declares model_id as
    a real WorkflowParameter, and adde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
2026-07-19 docs(ml): document backend switching, workflow parameters, and verified E2E
    The README still described things that later turned out to be false:
    - "Giả định chưa kiểm chứng" about the coordinate space - it has since been
    verified against the live API (response dims == local decode dims).
    - The response was described as a flat list. It is not: Roboflow wraps results
    in an "outputs" envelope, and missing that made a correctly-configured
    predictions_key resolve zero particles - a silent clean-water reading.
    - The E2E section was labelled "CHƯA chạy được ở đây". It has now been run.
    Also documents what was not written down anywhere: that the two directions are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
2026-07-19 docs(ml): add quickstart, record the workflow in use, ground Direction 1 status
    The run steps were spread across the E2E section and the config section, so
    "how do I just run this" had no single answer. Adds a three-step quickstart.
    Also states which Roboflow workflow is actually in use (aqua-scope-infer) and
    that the leftover "...-logic" workflow is broken and should be deleted in the
    UI, since the API has no delete endpoint - and that the platform-managed base
    workflow should NOT be deleted.
    Direction 1 said only "not implemented"; it now lists what is actually missing
    (no weights, no ultralytics, no dataset script) so switching to backend=local
    does not look like a bug when it refuses t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
2026-07-19 docs(plan): siết assertion của test brownout (>=1 luôn đúng, không bao giờ fail)
2026-07-19 feat(firmware): dựng aqua_scope_station, tắt đèn flash khi chụp
    Đèn flash GPIO4 chiếu từ trên xuống làm hỏng ảnh backlit silhouette.
    [partitions.csv]
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2026-07-19 fix(firmware): strncpy tự bảo đảm null-terminate; đính chính lý do validate device_id
    Review Task 2 bắt được hai điều:
    - Nhánh đọc NVS dựa vào static zero-init thay vì tự đóng null.
    - Spec/plan ghi SAI rằng web dùng device_id làm tên file ảnh. Tên file
    dựng từ sample_code; device_id không có validator phía server.
    Validate vẫn đúng hướng nhưng là phòng thủ, không phải vá lỗ hổng.
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2026-07-19 fix(firmware): chặn đọc ngoài mảng resolution[] và mở value[] đủ 64 ký tự device_id
    - device_handler: framesize_t từ s->status.framesize không được validate ở
    cmd_handler (var=framesize dùng thẳng atoi không kiểm tra), nên phải tự
    chặn bounds trước khi dùng làm chỉ số resolution[]; ngoài [0,
    FRAMESIZE_INVALID) thì lùi về FRAMESIZE_UXGA thay vì đọc rác/crash.
    - cmd_handler: value[32] cắt cụt mọi device_id >=32 ký tự (httpd_query_key_value
    trả ESP_ERR_HTTPD_RESULT_TRUNC, bị bắt ở nhánh lỗi chung nên nhánh
    device_id không bao giờ chạy tới), làm thông báo 400 "dài 1..64" nói sai
    sự thật. N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
    [app_httpd.cpp]
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2026-07-19 fix(firmware): sửa boot loop vô tận do watchdog cấu hình sai
    Core esp32 3.x đã tự init sẵn TWDT lúc boot (timeout mặc định 5s,
    trigger_panic bật). setup() gọi esp_task_wdt_init() lần hai để set
    timeout 30s nhưng bỏ qua mã lỗi trả về (ESP_ERR_INVALID_STATE) — nên
    timeout 30s không hề được áp dụng, watchdog thực tế vẫn là 5s. Trong
    khi đó loop() delay(10000) một cục giữa hai lần esp_task_wdt_reset().
    10s > 5s -> panic -> reset -> setup() chạy lại -> panic tiếp: board
    reset liên tục mỗi ~5s, không bao giờ phục vụ được ảnh (biên dịch vẫn
    sạch 100%, lỗi chỉ lộ ra khi chạy thật trên board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
    [aqua_scope_station.ino]
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2026-07-19 docs: đánh dấu --from-board là chức năng chưa có
    Checklist mục 6-7 bảo chạy ml.infer --from-board, nhưng cờ đó chưa tồn tại
    (Task 8 mới thêm). Ai chạy bây giờ sẽ gặp unrecognized arguments và
    không biết đó là "chưa tới lượt" hay bug firmware.
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2026-07-19 test(ml): [station] test phải thật sự fail được
    Ban dau test dung gia tri TRUNG DEFAULTS, ma _read_toml nuot loi
    file-not-found -> test luon xanh ke ca khi file khong he duoc doc.
    Gio dung tmp_path voi gia tri KHAC DEFAULTS. Them test ep kieu env var
    cho timeout_s/retries (int) va interval_s (float).
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2026-07-19 fix(ml): chống trùng sample_code bằng cấu trúc + bổ sung test cho các ca hỏng
    sample_code trước đây chỉ dựa vào độ phân giải mili-giây của đồng hồ.
    Hai khung rơi cùng một mili-giây -> ingest coi khung sau là bản retry và
    trả already_exists -> MẤT DỮ LIỆU ÂM THẦM trong sổ audit. Giờ
    _next_sample_code() nhớ các mã đã phát trong lượt đo và thêm hậu tố phân
    biệt khi trùng.
    Bổ sung test cho các nhánh trước đây chưa bao giờ chạy:
    - JPEG cụt (có magic đầu, thiếu marker kết thúc)
    - /device trả HTML / JSON không phải object / HTTP 500
    - sample_code không trùng khi đồng hồ đứng y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
2026-07-19 fix(ml): sửa 2 lỗi Task 8 review - check-config mâu thuẫn + crash encoding
    - config.missing_for("station") giờ nhận station_host tùy chọn: cli.py
    truyền vào host hiệu dụng (đã áp cờ --from-board > env > config.local >
    config), nên --check-config --from-board <ip> không còn tự báo
    "station.host chưa đặt" trong khi vừa in ra host hợp lệ ngay phía trên.
    - Thêm ml/infer/encoding_utils.force_utf8_output(), gọi đầu main() trong
    cli.py, để print() các thông báo lỗi tiếng Việt (StationError, ...) không
    làm crash UnicodeEncodeError trên console Windows mặc định cp1252. Nhân
    bản (không import chéo) từ dataset_coll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
2026-07-19 fix(ml): sửa mất mẫu âm thầm khi board hỏng toàn bộ khung + 4 finding nhỏ
    CRITICAL (đã tái hiện thật): board trả 503 cho mọi khung ở --from-board
    --count N khiến Summary báo "0 failed"/RC=0 dù KHÔNG mẫu nào được ghi vào
    sổ audit truy xuất nguồn gốc. Esp32CaptureSource._capture_once() bỏ khung
    hỏng bằng print()+continue mà không đếm, nên cli.py không có cách nào biết
    khung đó từng tồn tại.
    - source.py: Esp32CaptureSource.skipped đếm khung bị bỏ; cli.py cộng vào
    Summary và trả RC != 0 khi có khung mất — theo đúng khuôn mẫu đã có sẵn
    cho `collisions`.
    - Khóa lại bằng test: ml/tests/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
2026-07-19 fix(firmware): tôn trọng fallback không-PSRAM + validate framesize + escape SSID
    IMPORTANT #1: nhánh không-PSRAM trong initCamera() (aqua_scope_station.ino)
    tự hạ FRAMESIZE_SVGA + CAMERA_FB_IN_DRAM kèm cảnh báo, nhưng
    aquaPrefsApplyDefaults() gọi set_framesize(s, UXGA) vô điều kiện ngay sau
    đó, dỡ bỏ đúng fallback vừa dựng — buffer DRAM không đủ cho UXGA, ảnh cụt.
    aquaPrefsApplyDefaults()/aquaPrefsLoad() giờ nhận thêm tham số max_framesize
    (setup() tính từ psramFound(), giống initCamera()) và tự clamp xuống đúng
    trần bộ nhớ trước khi chạm sensor. aquaPrefsReset() (gọi từ /control?
    var=reset) cũng được sửa t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
    [app_httpd.cpp, aqua_scope_station.ino]
2026-07-23 feat(openscad): hằng số + assert an toàn hạt cho cụm chống sóng khay
    [constants.scad]
2026-07-23 fix(openscad): sửa 2 lỗi assert an toàn hạt cụm chống sóng
    - Assert vách cong cũ (baffle_r_mid + baffle_t/2 < tray_inner/2 - 0.01)
    không bao giờ có thể fail vì assert hành lang (baffle_corridor) chạy
    trước và đã ép baffle_r_mid + baffle_t/2 <= 17.0, luôn nằm trong biên
    19.99 của assert cũ. Thay bằng assert chặn vách đẩy quá sâu vào trong:
    vùng ảnh còn lại (đường kính trong của vách) phải ≥25mm.
    - Thêm assert còn thiếu cho chiều cao cửa sổ vào (inlet_slot_h): đây
    cũng là kích thước hạt phải chui qua, phải ≥1.5× hạt như inlet_gap_w,
    nhưng thiết kế cũ (1 khe 20×3) không cần as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
    [constants.scad]
2026-07-23 feat(openscad): flow_tray_003 - cửa vào đục lỗ 4 cửa sổ thay khe liền 20x3
    [flow_tray_003.scad]
2026-07-23 docs(flow-tray): sửa 2 lỗi comment → x=-22.2 chính xác + ghi lệch thứ 5
    - Sửa lệch 1: comment mô tả mặt cuối khoang loe sai (ghi x=-21.8 nhưng đúng
    là x=-22.2, do khối hull sâu 1.0); thêm giải thích liên tục dòng chảy qua
    overlap với inlet_windows()
    - Sửa lệch 2: thêm ghi chú ở header về lệch thứ 5 file-local (khoam loe sâu
    1.0 thay 1.4)
    - Xác nhận: chỉ comment thay đổi, hình học không đổi; export-stl PASSED
    [flow_tray_003.scad]
2026-07-23 feat(openscad): vách cong tiêu năng r16.4 cao 7mm, hành lang hạt 3.0mm
    Thêm module arc_baffle() + tray_internals() vào flow_tray_003.scad, union
    2 tầng (tray_shell ∪ tray_internals) SAU khi lòng Ø40 đã được khoét, để
    vách cong không bị lệnh khoét lòng xóa mất. Vách chắn đường thẳng cổng
    vào → cổng ra, ép nước đi vòng qua hành lang 3.0mm ở 2 đầu mút. Sửa luôn
    lỗi chính tả "khoam loe" → "khoang loe" trong header.
    Đã kiểm: echo constants xác nhận hanh_lang=3mm (1.5x hạt 2mm), vung anh
    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
    [flow_tray_003.scad]
2026-07-23 feat(openscad): miệng loe bellmouth R3 cổng ra chống dồn ứ dội sóng
    [flow_tray_003.scad]
2026-07-23 fix(openscad): sửa thành mỏng knife-edge tại miệng loe bellmouth
    bell_outer() cũ dịch bán kính bell_r(a)+bell_wall tại cùng góc a — không
    phải offset pháp tuyến thật. Tại miệng loe (a=0), tiếp tuyến biên dạng là
    RADIAL nên phép dịch này suy biến gần về 0: reviewer đo được thành thật
    chỉ còn 0.231mm, dưới cả 1 lớp nozzle 0.4mm, in ra sẽ tưa mép hoặc gãy —
    mảnh vỡ trở thành rác trong hệ thống mà ràng buộc cứng #1 là "mọi hạt phải
    ra hết, không gì được kẹt".
    Sửa bằng offset(r=bell_wall) (offset pháp tuyến thật của OpenSCAD) trên
    biên dạng 2D dùng chung (bell_profile_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
    [flow_tray_003.scad]
2026-07-23 fix(openscad): bỏ clamp y>=0 mở lại miệng loe bellmouth bị bịt
    offset(r=bell_wall) bo tròn góc nhọn tại miệng loe (a=0) quét vật liệu
    tràn xuống y<0 trên suốt bề rộng miệng; do bell_void() không có hình
    học ở y<0, difference() không khoét được phần tràn này nên nó bịt đặc
    miệng loe (đo được X=15.8..16.9 đặc hoàn toàn). Kẹp thêm y>=0 sau
    offset() loại bỏ đúng phần tràn, mở lại miệng loe.
    Verify: projection(cut=true) tại X=15.5/16.0/16.5 xác nhận miệng nay
    rỗng hoàn toàn (trước fix có vật liệu thật, đã dựng control test đối
    chứng); lòng Ø6 thông suốt X=17..21 (5.997mm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
    [flow_tray_003.scad]
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2026-07-24 fix(openscad): nối vách cong chống sóng vào thành khay bằng gờ trên mực nước
    arc_baffle() không chạm gì (đáy khay hở, hành lang 3mm cố ý hở với thành,
    bellmouth ở phía đối diện) → CGAL báo Volumes=3, in ra thành mảnh nhựa rời
    trôi vào lòng khay rồi kẹt cổng ra Ø6 — đúng thứ cụm chống sóng phải ngăn.
    Thêm 3 gờ nối vách↔thành tại 150/180/210°, đặt Ở TRÊN MẶT NƯỚC
    (z = water_depth..baffle_h, vách vốn cao hơn nước 1mm đúng cho mục đích
    này) nên hạt ngập nước không bao giờ chạm gờ; hành lang 3.0mm vẫn thông
    suốt trọn vẹn ở z=0..water_depth (kiểm bằng kh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
    [constants.scad, flow_tray_003.scad, print_flow_tray.stl]
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2026-07-24 fix(pump_pwm_test): sua hai loi blocking ramp va in printf
    1. PHAN 1 (QUAN TRONG): Thay doi thoi diem bat dau dong ho pha.
    Truoc day phaseStartMs = millis() chay TRUOC khoi ramp-up, nen thoi gian vuot
    duoc tinh vao thoi gian pha, tao ra am lenh. Vi du fillMs 5000ms voi rampUpMs
    250ms chi co thuc te ~4750ms o muc cruise. Sau sua, timestamp bat dau SAU khi
    bom dat toi muc tieu, toan bo thoi gian cau hinh duoc su dung o muc cruise/
    flush. Giu ramp-down truoc timestamp cho cac pha stop-pump de bao dam static
    window trong SETTLING.
    2. PHAN 2 (NHAN): Sua %% -> % trong println() o printHelp().
    %% chi escape trong printf-style format; println() in ra literal %%. Doi thanh
    %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
    [pump_pwm_test.ino]
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2026-07-24 feat(openscad): thêm hằng số + assert cho trạm bơm gọn (đế liền + hộp L298N + kẹp bơm)
    [constants.scad]
2026-07-24 feat(openscad): thêm component pump_station_001 - đế liền + hộp L298N + yên kẹp bơm
    [pump_station_001.scad]
2026-07-24 feat(openscad): xuất STL print_pump_station (đế + hộp L298N + yên kẹp bơm)
    [print_pump_station.scad, print_pump_station.stl]
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2026-07-25 feat(openscad): tách l298n_box_clr theo trục X/Y + thêm hằng số kênh dây liền mạch
    Chuẩn bị cho pump_station_002 (giấu dây jumper) — spec 2026-07-25.
    [constants.scad]
2026-07-25 feat(openscad): pump_station_002 — kênh giấu dây liền mạch + hộp L298N nới bất đối xứng
    Thay rãnh dây ngắn (chỉ hộp↔yên gần) bằng kênh liền mạch có nắp đậy rời chạy
    suốt qua cả 2 yên kẹp; mỗi yên kẹp thêm khe đáy nối lòng máng↔kênh (lắp bơm
    chiều nào cũng có lối thoát dây); khe OUT động cơ hạ xuống mức sàn nối thẳng
    vào kênh thay vì hở miệng hộp rồi vòng xuống ngoài.
    [pump_station_002.scad]
2026-07-25 fix(openscad): pump_station_002 — sửa non-manifold khi 2 yên kẹp cùng đè lên kênh dây
    2 vấn đề tìm được qua export-stl cô lập từng phần:
    - Khe OUT động cơ hạ xuống mức sàn (z=0) trùng khít tuyệt đối với mặt đáy hộp
    L298N — trùng mặt phẳng gây non-manifold khi boolean.
    - Khối yên kẹp bơm chạm khít z=0 với mặt đế đã bị khoét kênh dây — chỉ lộ ra khi
    CẢ 2 yên kẹp cùng đè lên kênh liền mạch (1 yên kẹp không lỗi, 2 mới lỗi).
    Cả 2 sửa bằng cách nới -EPS để solid CHỒNG LẤN thay vì chạm khít, theo đúng
    pattern EPS đã dùng sẵn trong file (không ảnh hư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
    [print_pump_station.scad, print_pump_station.stl, pump_station_002.scad]
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2026-07-26 feat(firmware): trả mặc định camera về auto exposure + hạ XCLK xuống 8MHz
    Phần code của spec 2026-07-25 (commit 0bf83ff chỉ có tài liệu): bỏ ép tắt
    AEC/AEC-DSP/AGC lúc boot và lúc ?var=reset, thêm ?var=darkmode để áp cả preset
    buồng tối bằng một lệnh.
    XCLK 20MHz gây artifact ảnh trên nhiều module OV2640 (espressif/esp32-camera#150);
    lấy 8MHz theo dataset_collector/firmware vốn chạy sạch trên chính board này.
    Đánh đổi tốc độ khung không quan trọng với trạm Stop-Flow (1 khung/chu trình).
    [app_httpd.cpp, aqua_scope_cam.ino, aqua_scope_station.ino]
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2026-07-26 fix(web): stop() phải join xong mới quên thread, siết timeout StationClient
    stop() từng xoá self._thread/self._stop_event TRƯỚC khi join, nên board treo
    giữa một lệnh HTTP (StationClient mặc định timeout_s=20/retries=3) có thể
    khiến join(5.0) hết giờ mà stop() vẫn coi như xong — start() kế tiếp không
    còn thấy thread cũ còn sống nên spawn thread thứ hai đè lên cùng station,
    hai thread cùng ghi vào state không khoá.
    - stop(): chỉ xoá handle khi join xác nhận thread đã chết (guard bằng
    identity check để không xoá nhầm thread mới của một start() đang chạy
    song song); nếu join hết giờ, giữ nguy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
2026-07-26 fix(web): control panel review round 1 - real chip/mono/danger tokens, poll guard, 422 handling
    Fixes six review findings against the panel added in a8a4eac:
    - add missing .chip and bare .mono base CSS rules
    - fix --text-dim typo to --text-3
    - add poll() in-flight guard so a slow board cannot stack requests
    - normalize pydantic 422 array `detail` into a readable message
    - add real theme-aware --danger* tokens, drop hardcoded warning colors
    - give flash() messages a grace window so the 1s poll can't erase them
2026-07-26 fix(web): route btn-probe error through detailToMessage() (finding 4 round 2)
    Round-1 fix wired detailToMessage() into post() but missed the btn-probe
    handler's separate inline fetch, which still stringified a pydantic 422
    detail array as [object Object]. Route it through the same helper.
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2026-07-26 feat(workflow): update start.bat error handling, esp32-cam submodule & add pump station v2 plan/verify files
    [pump_station_wire_path_001.scad]
2026-07-26 fix: btn-save short-circuit, start.bat error handling, README launcher docs
    - control_panel.js: never gate the Save-to-flash POST on prefs_saved
    (sticky NVS "ever saved" flag, not "current settings saved") — it was
    silently dropping every save after the first.
    - start.bat: check errorlevel after spawning the server PowerShell window
    and fail loudly with a pause instead of exiting silently; use %~dp0
    instead of %CD% for the script path so it no longer depends on the
    earlier cd /d having run first.
    - README.md: document that start.bat now opens a separate "Aqua Scope
    Server" window and exits, and that stopping the server means Ctrl+C or
    closing that window, not the one that alr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
2026-07-26 docs: add design spec for real MJPEG live-view on /stream page
    Replaces the pure-frontend canvas demo (never connected to real hardware)
    with an <img> pointed at the board's existing MJPEG server on port+1.
2026-07-26 feat(web): replace /stream canvas demo with real MJPEG live-view
    The old /stream page was a pure-frontend canvas animation with randomly
    spawned fake particles — it never called the backend or a real board,
    despite reading as a live camera feed. Users expecting real footage saw
    it "stuck" showing only the scripted demo.
    Firmware already runs a second http server at server_port+1 (default 81)
    serving multipart/x-mixed-replace at /stream (app_httpd.cpp), which a
    plain <img> decodes natively. stream_live.js reads station_host from the
    existing /api/settings and points the <img> straight at the board over
    the LAN — no backend proxy, no new API route. Handles three states: no
    host configured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
2026-07-26 fix: pump-button highlight race + dashboard auto-refresh on new sample
    Pump on/off buttons: clicking one now updates both buttons' highlight
    state synchronously and holds that optimistic state for up to 6s (or
    until the board's own /device snapshot confirms it), instead of letting
    the very next 1s poll flip the highlight back based on a stale board
    report that hasn't caught up to the just-sent command yet — the
    "sáng lộn bên" flicker.
    Dashboard ("Mẫu mới nhất" card, "5 mẫu gần nhất" table, metric tiles):
    these are server-rendered once at page load with no client-side refresh
    of their own. control_panel.js now reloads the page automatically the
    moment a new written (Đo mod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
2026-07-27 fix(ml/web): filter bubble class from particle count, forward roboflow confidence, fix measure-mode preview; docs: ESP32-CAM/OV2640 baseline update
    Reconciles docs (CLAUDE.md, README, HUONG_DAN_LAP_RAP, ai_model_plan, variants) with the ESP32-CAM (OV2640) hardware switch, adds bubble-class exclusion from particle counts/QC warnings, forwards roboflow.confidence into workflow inputs, and keeps the control-panel preview populated during measure-mode runs.
